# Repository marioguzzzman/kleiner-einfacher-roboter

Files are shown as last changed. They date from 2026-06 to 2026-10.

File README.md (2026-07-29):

# Mini Robot Swarm Unit — "Little Dog"

A small 3D-printed quadruped robot, built as one unit of a larger robotic swarm.
Each unit senses its surroundings, moves on four servo legs, and (from v2 onward)
has a synthesized "voice." This repository holds **two hardware/firmware
generations** of the same physical robot plus the **shared** mechanical body and
carrier PCB.

> The 3D body and the carrier PCB are common to both generations — only the
> microcontroller board and the firmware changed between v1 and v2.

---

## Two generations

| | **v1** | **v2** |
|---|---|---|
| Folder | [`v1/`](v1/) | [`v2/`](v2/) |
| MCU | Adafruit Feather ESP32 V2 | ESP32-C3 SuperMini |
| Servos | 4× MG90S | 4× MS18 (SG90-class) |
| Sensing | HC-SR04 ultrasonic | HC-SR04 ultrasonic (+ 1k/2k echo divider) |
| Audio | — | MAX98357A I2S amp + speaker ("modem voice") |
| Behavior | pose-based (sit / wave / walk / lay down) | trot + obstacle-stop (<10 cm) + voice on stop |
| I2C pins | GPIO21/22 | GPIO6/7 |
| Status | Phase 1 baseline | **electronics bring-up complete** |

**v2 is a continuation of v1**, not a separate project — same robot, new brain.

---

## Repository layout

```
kleiner-einfacher-roboter/
├── README.md                       ← you are here
├── LICENSE
├── robot_dog_pcb/                   KiCad carrier PCB          (SHARED)
├── little_robot_original_3d_stl/    printable body/legs/cover  (SHARED)
├── v1/   Feather ESP32 V2, pose-based
│   ├── README.md
│   ├── docs/          hardware.md · setup.md · code_explanation.md
│   └── src/           robot_dog.ino
└── v2/   ESP32-C3 SuperMini, walk + sensor + voice
    ├── README.md
    ├── firmware/
    │   ├── little_dog_walk/     ⭐ main program (walk + stop + voice)
    │   ├── little_dog_test_1/   full 5-part functionality test
    │   ├── little_dog_test_v2/  flag-based staged test
    │   ├── obstacle_stop/       walk + stop demo (simple chirp)
    │   └── diagnostics/         per-subsystem isolation sketches
    └── docs/          HANDOFF_WIRING.md · HANDOFF_LEARNINGS.md
```

---

## Shared hardware

- **Body:** `little_robot_original_3d_stl/` — `main_body.stl`, `leg.stl`, `cover.stl`.
  Based on the [Cobot Four-Servo-Legs Robot](https://makerworld.com/en/models/523448-cobot-four-servo-legs-and-distance-sensor-robot) on MakerWorld.
- **Carrier PCB:** `robot_dog_pcb/` — KiCad project (schematic, board, `.pdf` export).
  Modules mount as pluggable headers on the carrier.

---

## Getting started

- Building the **current** robot → see **[v2/README.md](v2/)** and
  [v2/docs/HANDOFF_WIRING.md](v2/docs/HANDOFF_WIRING.md) for the full wiring schematic.
- The **original** design → see **[v1/README.md](v1/)**.

---

## License

See [LICENSE](LICENSE). (Original note: all rights reserved.)

## Credits

- 3D model: [Cobot Four Servo Legs Robot](https://makerworld.com/en/models/523448-cobot-four-servo-legs-and-distance-sensor-robot) on MakerWorld
- Built with Arduino / ESP32, PCA9685, MAX98357A, and Adafruit libraries.

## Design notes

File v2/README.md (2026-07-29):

# v2 — ESP32-C3 SuperMini rebuild (walk + obstacle-stop + voice)

Second generation of the Little Dog quadruped. Same 3D body as
[v1](../v1/), but rebuilt around an **ESP32-C3 SuperMini** and given a
**synthesized voice** (a dial-up-modem "handshake") via an I2S amplifier.
Electronics bring-up is **complete and verified** — the robot trots, freezes
when something comes within 10 cm, and "speaks" when it stops.

> Full wiring (ASCII schematic, power rails, common-ground star) and the
> debugging lessons live in **[docs/HANDOFF_WIRING.md](docs/HANDOFF_WIRING.md)**
> and **[docs/HANDOFF_LEARNINGS.md](docs/HANDOFF_LEARNINGS.md)**. Read those first.

---

## Hardware

| Component | Role |
|---|---|
| ESP32-C3 SuperMini | MCU (USB-C, 3.3 V logic) |
| PCA9685 (HW-170) | 16-ch PWM servo driver, I2C @ **0x40** |
| 4× MS18 micro servos | legs (fore/aft swing) |
| HC-SR04 + 1k/2k divider | distance sensor ("eyes") |
| MAX98357A + speaker | I2S mono amp — the "voice" |
| 5 V bench supply (~3 A) | servo power into PCA9685 V+ |

## Pin map (ESP32-C3)

| GPIO | Net | | GPIO | Net |
|---|-----|-|---|-----|
| 0 | HC-SR04 TRIG | | 6 | PCA9685 SDA |
| 1 | HC-SR04 ECHO (÷) | | 7 | PCA9685 SCL |
| 3 | MAX98357A BCLK | | 10 | (unused — ex-OE) |
| 4 | MAX98357A LRC | | | |
| 5 | MAX98357A DIN | | | |

Power: PCA9685 **VCC ← 3.3 V** (logic) and **V+ ← 5 V** (servos) are separate.
MAX98357A **SD → 3.3 V** (enable), **GAIN → GND** (15 dB). **All grounds common**,
including the bench supply's negative. See the schematic in `docs/`.

---

## Firmware

Flagship program: **`firmware/little_dog_walk/`** — trots via diagonal pairs,
freezes all legs when an obstacle is within `STOP_CM` (10 cm), and plays the
modem-handshake voice on the stop edge. Tunables at the top: `g_volume`,
`SWING`, `STOP_CM`, cadence `delay()`.

| Sketch | Purpose |
|---|---|
| `little_dog_walk/` | ⭐ main: walk + obstacle-stop + modem voice |
| `little_dog_test_1/` | full 5-part test (center → per-leg → trot → distance → chirp) |
| `little_dog_test_v2/` | flag-based staged test (`TEST_LEGS/DISTANCE/AUDIO`) |
| `obstacle_stop/` | earlier walk+stop demo with a simple two-tone chirp |
| `diagnostics/esp32_alive/` | bare MCU sanity + LED blink |
| `diagnostics/motors_only/` | PCA9685 + servo sweep in isolation |
| `diagnostics/hold_center/` | park servos, measure holding current |
| `diagnostics/distance_only/` | HC-SR04 raw pulse + cm |
| `diagnostics/audio_only/` | amp test + I2S bytes-written diagnostic |
| `diagnostics/modem_chirp/` | standalone dial-up "voice" for tuning |

The `diagnostics/` sketches exist so each subsystem can be verified alone —
invaluable when something doesn't work (see the learnings doc).

---

## Build & flash

**Board:** ESP32C3 Dev Module. **Critical:** set **`USB CDC On Boot → Enabled`**
or the USB-C serial monitor stays blank.

Arduino IDE → Tools → Board → *esp32* → **ESP32C3 Dev Module**, then
`USB CDC On Boot: Enabled`, pick the port, Upload.

CLI equivalent:
```bash
arduino-cli compile --fqbn esp32:esp32:esp32c3:CDCOnBoot=cdc firmware/little_dog_walk
arduino-cli upload  -p COM3 --fqbn esp32:esp32:esp32c3:CDCOnBoot=cdc firmware/little_dog_walk
```
Libraries: **Adafruit PWM Servo Driver** (+ Adafruit BusIO). I2S uses the
built-in ESP32 `driver/i2s.h`.

---

## What changed from v1

- MCU **Feather ESP32 V2 → ESP32-C3 SuperMini** (3.3 V logic, native USB-C).
- I2C moved to **GPIO6/7** (v1 used 21/22); OE left unconnected (onboard pulldown).
- Added the **MAX98357A "voice"** and the **obstacle-stop** behavior.
- Servos **MG90S → MS18**; distance echo now through a **1k/2k divider**.

## Status / next

Bring-up done. Remaining before a proper directional gait:
**verify the leg map** (which PCA9685 channel drives which physical leg, and swing
direction) — run `little_dog_test_1` Part 2 and watch. Then add per-servo
direction sign + per-leg center trim. See `docs/HANDOFF_LEARNINGS.md`.

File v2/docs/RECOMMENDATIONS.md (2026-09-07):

# Recommendations — preparing to work on this project

A practical checklist for flashing and running the Little Dog (v2, ESP32-C3
SuperMini). Read this before a bench
session. Wiring details live in [HANDOFF_WIRING.md](HANDOFF_WIRING.md); the
*why* behind the gotchas is in [HANDOFF_LEARNINGS.md](HANDOFF_LEARNINGS.md).

---

## 1. Before you power on

- **Bench 5 V supply ON** into PCA9685 **V+** (servo power), limit ~3 A.
- **Common ground joined** — the bench supply's **(−) must tie into the same
  ground node** as the ESP32, PCA9685, sensor, and amp. If it doesn't, the
  servos get power but no valid signal and sit slack (looks like dead code, is
  actually wiring). See [HANDOFF_WIRING.md:93](HANDOFF_WIRING.md#L93).
- **Use a real USB *data* cable** (not charge-only), seated firmly. The
  SuperMini's USB-C jack is fragile — a flaky cable/connector is the #1 cause of
  the "port goes in and out."

## 2. Arduino IDE board setup

- **Board:** Tools → Board → **`esp32`** group (Espressif Systems) →
  **ESP32C3 Dev Module**. *Not* the "Arduino ESP32 Boards" group.
  - Confirm you're on the Espressif core: the Tools menu should show
    **USB CDC On Boot**, Flash Size, Partition Scheme, etc. If those options
    aren't there, you picked the wrong core.
- **USB CDC On Boot → Enabled.** Critical — without it the Serial Monitor stays
  blank on this board.
  - ⚠️ This is a **compile-time** option. Flipping the menu does nothing until
    you **re-upload** a sketch built with it enabled.
- **Baud:** Serial Monitor at **115200**.

## 3. If the COM port won't stay put

The SuperMini uses **native USB (USB-Serial/JTAG)**, so every reset
re-enumerates the port — it can appear to drop "in and out," and the COM number
hops on replug (we've seen COM3 / COM5 / COM9). This is expected behavior, not a
fault. Also try a **rear/motherboard USB port**, not a hub or front-panel port.

## 4. Uploading — force download mode

When a normal upload can't catch the cycling port, put the board into bootloader
mode by hand. This holds a stable port that doesn't run user code:

1. **Hold BOOT** (GPIO9) — keep holding.
2. While holding BOOT, **tap RESET** once, then release RESET.
3. **Release BOOT.** Now upload.

Order matters — BOOT must be held **across** the reset pulse; pressing both at
once does nothing. (One-button boards: hold BOOT while plugging in the USB.)

## 5. After the upload

- **"Hard resetting via RTS pin…" is normal** — it's just esptool pulsing reset
  so the chip boots your new sketch. Not an error.
- That reset **re-enumerates the USB port**, so the Serial Monitor from the
  upload is now stale. **Reselect the current COM** (re-check the port list) and
  **reopen the monitor at 115200**. Tap RESET once if nothing appears.

## 6. Verifying it actually works

- Serial Monitor should show `=== MOTORS-ONLY test ===` then
  **`found 0x40`** — that line confirms I2C + the PCA9685 are alive.
  `NONE found!` instead = SDA/SCL wiring or PCA9685 power, not the code.
- **Watch the legs, not just the log.** If servos sweep but the monitor is
  blank, the diagnostic is *passing* — only the logging is misrouted (see §2,
  USB CDC On Boot).
- Use the **`diagnostics/`** sketches to isolate one subsystem at a time
  (`motors_only`, `distance_only`, `audio_only`, …) — much faster than debugging
  the full `little_dog_walk` firmware.

## 7. Blank Serial Monitor — quick triage

1. Reopen the monitor on the **current** COM at **115200** (tap RESET first).
2. Still blank → **USB CDC On Boot = Enabled**, then **re-upload** (compile-time).
3. Still blank but **legs move** → the sketch is running; logging is on UART0
   (GPIO20/21), not USB. Fix via step 2.

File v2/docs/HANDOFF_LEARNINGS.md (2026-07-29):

# HANDOFF — Little Dog (unit #1) — WHAT WE LEARNED
Last updated: 2026-07-29 — bring-up + debugging session.
Companion: `HANDOFF_WIRING.md` (the physical wiring).

---

## HEADLINE
Full electronics bring-up is **DONE**. The robot walks, stops when something is
within 10 cm, and plays a dial-up-modem "voice" when it stops. Every subsystem
is verified working. The main remaining task is **leg-map verification** before a
real directional gait can be written.

---

## KEY LEARNINGS / GOTCHAS (in the order they bit us)

1. **PCA9685 OE has an onboard pull-down → leave OE UNCONNECTED.**
   Half-wired/floating OE was the cause of the long "servos only twitch" saga.
   Outputs are enabled by default. (Confirmed on Adafruit's pinout page.)

2. **"Servos twitch / don't move" with I2C working = signal/ground, not power.**
   Diagnosis ladder that worked:
   - I2C finds 0x40 → command path OK.
   - Servo **draws ~13 mA and sits slack** → NO valid PWM reaching it.
     A servo that's actually being driven **holds firm** and draws **100–200 mA**.
   - "Hold at center" test + feeling the horn (firm vs slack) is the fastest check.

3. **Bench-supply current is a LIMIT, not a push.**
   Raising the amp knob does not force current into the servos — they draw what
   they need. Setting it too LOW makes the supply fold back (voltage sags → twitch).
   Set the limit high (≈3 A) and keep **voltage at 5.0 V**.

4. **Common ground is mandatory between the bench supply and the ESP32.**
   Two separate power sources → the servo PWM needs a shared ground reference.
   Missing common ground = powered but slack servos.

5. **USB CDC On Boot must be ENABLED** for the SuperMini's USB-C serial.
   Default is Disabled → Serial goes to UART pins → **blank Serial Monitor**.
   FQBN: `esp32:esp32:esp32c3:CDCOnBoot=cdc`. Baud 115200.

6. **The I2S chirp hung the whole sketch.**
   `i2s_write(..., portMAX_DELAY)` blocks FOREVER if the buffer isn't draining,
   which froze the loop so Parts 4 & 5 (and even leg names) never printed.
   **Fix:** use a finite timeout `pdMS_TO_TICKS(50)` and bail if `bw==0`.
   Also: print the label BEFORE the sensor read, so a slow read can't hide it.

7. **MAX98357A silence debugging:**
   - **SD pin must be tied to 3.3V to ENABLE the amp.** It has an internal
     pull-down, so floating = shutdown = silent. A floating SD can even read a
     phantom 3.3V on a multimeter — don't trust it, wire it solidly.
   - Needs **all three** I2S lines: BCLK, LRC, DIN. Missing LRC = silent.
   - Its class-D output is **not measurable with a DMM** (balanced ~300 kHz PWM).
     Trust your ears, not the meter, on OUT+/OUT-.
   - **GAIN pin = hardware volume** (GAIN→GND = 15 dB max). Not software-settable.
   - **Software volume = scaling the sample amplitude** (`g_volume` 0..1). Both
     stages multiply: software amplitude → hardware GAIN → speaker.
   - Speaker is only 8Ω **0.25 W** — fine for brief chirps; a 4Ω 3W speaker later
     would be much louder and safer at full gain.
   - **Confirmed:** GAIN→GND (15 dB) is wired and works, `g_volume=1.0`, yet it's
     still not very loud — the **small speaker is the ceiling**, not the amp or
     the code. A slightly bigger speaker helped only marginally; a real 4Ω 3–5W
     driver in an enclosure is the fix if more volume is ever needed.

8. **I2C on GPIO6/7 works** and avoids the C3 strapping pins (GPIO2/8/9).
   One reference calls 6/7 "SPI-default," but `Wire.begin(6,7)` remaps fine and
   0x40 is found reliably. Only move it if you ever see I2C dropouts.

9. **Serial-read trick (for scripted reads):** on the C3's USB-JTAG, RTS = reset.
   Open the port with **RTS de-asserted** to avoid rebooting the board into the
   bootloader; the COM number also changes on replug (COM3 ↔ COM5).

---

## THE LITTLE PROGRAMS (sketch inventory)
All live as sibling folders in `C:\Users\mario\Downloads\`.

| Sketch | What it does (briefly) |
|---|---|
| **little_dog_walk/** | ⭐ FLAGSHIP. Trots (diagonal pairs); freezes all legs when something <10 cm; plays the modem-handshake "voice" on the stop edge. Has the full audio engine + median distance. |
| **little_dog_test_1/** | Original 5-part functionality test: center → move each leg one at a time (prints leg name — USE FOR LEG-MAP) → diagonal-pair trot preview → distance print → chirp. I2S now hang-proofed. |
| **esp32_alive/** | Bare MCU sanity check — boots, prints chip info, blinks onboard LED (GPIO8). Proves the ESP32 alone works. |
| **hold_center/** | Parks all 4 servos at center and holds; prints I2C + heartbeat. Used to measure holding current (firm/100–200 mA vs slack/13 mA). |
| **motors_only/** | PCA9685 + servos only (no sensor/audio). Big slow sweep per channel, then all together. Isolates the servo path. |
| **distance_only/** | HC-SR04 only. Prints raw echo pulse (µs) + cm. Confirmed the sensor + divider work. |
| **audio_only/** | MAX98357A only. Loud continuous tone; prints I2S bytes-written per burst to tell "I2S OK but amp silent" from "I2S not running." |
| **modem_chirp/** | Standalone dial-up "voice" so the sound can be tuned by ear on a loop. This sound is now folded into little_dog_walk. |
| **obstacle_stop/** | Earlier version of the flagship: walk + stop-at-10cm with a SIMPLE two-tone chirp (before the modem voice was integrated). Superseded by little_dog_walk. |
| **little_dog_test_v2/** | Mario's own sketch — NOT created in this session and not reviewed here. Provenance/contents unknown to the bring-up agent. |

---

## DONE (2026-07-29)
- Verified ESP32, I2C/PCA9685 (0x40), all 4 servos, HC-SR04, MAX98357A audio.
- Root-caused & fixed: OE twitch (leave OE unconnected), I2S hang (finite timeout),
  silent amp (SD→3.3V + all 3 I2S lines), blank serial (USB CDC On Boot).
- Wired bench 5V straight to PCA9685 V+ (buck bypassed for now).
- Built the modem "voice" + integrated walk + obstacle-stop + voice.

## STILL PENDING / NEXT
- **Leg-map verification (BLOCKING a real gait):** run Part 2 of `little_dog_test_1`
  and record, for ch0–ch3, which physical leg moves and which way (front/back) first.
- **Directional gait:** once mapped, add per-servo direction sign (cancel L/R mirror)
  and per-leg center-trim offsets. Current "trot" is an uncalibrated preview.
- **Battery + buck:** final untethered unit still needs a power decision (buck back in,
  or a second buck for the ESP32). Not acquired yet.
- **Bigger speaker** (4Ω 3–5W in an enclosure) is the only real way to get more
  volume — GAIN→GND + g_volume=1.0 are already maxed; the speaker is the limit.

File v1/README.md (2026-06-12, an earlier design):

# Mini Robot Swarm Unit

A desktop companion robot powered by ESP32 with pose-based movement system. This robot features 4 servos for leg and arm movement, ultrasonic distance sensing, and smooth interpolated motion.

Robot Concept

## Table of Contents

- [Overview](#overview)
- [Features](#features)
- [Hardware Requirements](#hardware-requirements)
- [Wiring Diagram](#wiring-diagram)
- [Software Setup](#software-setup)
- [Calibration](#calibration)
- [Usage](#usage)
- [Documentation](#documentation)
- [Troubleshooting](#troubleshooting)
- [Future Work](#future-work)

---

## Overview

This project is a Phase 1 implementation of a desktop companion robot that can perform basic movements:
- Sit
- Wave
- Walk forward/backward
- Lay down

The robot uses pose-based control, allowing for easy extension of new movements and behaviors.

**Hardware:** Adafruit Feather ESP32 V2 + PCA9685 PWM Driver + 4x MG90S Servos + HC-SR04 Ultrasonic Sensor

---

## Features

- Pose-based movement system with smooth transitions
- Calibration mode via built-in button (SW38)
- Servo mirroring for mirrored limb configurations
- Distance sensor integration for reactive behavior
- Modular code structure for easy extension

---

## Hardware Requirements

| Component | Description | Quantity |
|---|---|---|
| Adafruit Feather ESP32 V2 | Main microcontroller | 1 |
| PCA9685 16-Channel PWM Driver | Servo motor driver | 1 |
| MG90S Microservos | 9g metal gear servos | 4 |
| HC-SR04 Ultrasonic Sensor | Distance detection | 1 |
| External 5V Power Supply (2A+) | Servo power | 1 |
| Jumper Wires | Dupont cables | Various |

**Source for 3D Model:** [Cobot Four Servo Legs Robot on MakerWorld](https://makerworld.com/en/models/523448-cobot-four-servo-legs-and-distance-sensor-robot)

---

## Wiring Diagram

### PCA9685 to Feather ESP32 V2

```
PCA9685                           Feather ESP32 V2
-------                           ---------------
VCC (Logic Power)    ------>      3V (3.3V output)
GND (Ground)         ------>      GND
SDA (I2C Data)       ------>      SDA (GPIO 21)
SCL (I2C Clock)      ------>      SCL (GPIO 22)
V+ (Servo Power)    ------>      External 5V Supply

Green Terminal (External Power):
  +5V  ----> External 5V Supply (+)
  GND  ----> External 5V Supply (-)
        +--> Feather GND (REQUIRED!)
```

### Servo Channel Assignment

```
PCA9685 Servo Channels:
+---------+
| CH0     | ----> Left Leg
| CH1     | ----> Right Leg
| CH2     | ----> Left Arm
| CH3     | ----> Right Arm
+---------+
```

### HC-SR04 Distance Sensor

```
HC-SR04              Feather ESP32 V2
------              -----------------
VCC      ------>    USB (5V)
GND      ------>    GND
TRIG     ------>    A3 (GPIO 4)
ECHO     ------>    A2 (GPIO 3)
```

### Power Distribution

```
+============================================================+
|                      POWER FLOW                         |
+============================================================+

   USB (PC)                         External 5V Supply
       |                                    |
       v                                    v
  +=========+                        +============+
  | Feather  |                        | Green     |
  | ESP32 V2 |                        | Terminal  |
  +=========+                        +============+
       |                                    |
       | 3V ----> VCC (PCA9685 logic)      |
       | GND ---+> GND (PCA9685)            |
       |        |--> External GND bridge     |
       |        +--> Feather GND (CRITICAL!)|
       |                                    |
       v                                    v
  +========================================+
  |          PCA9685 Servo Driver          |
  +========================================+
       |                    |
       v                    v
  Servo Power (V+)      CH0-CH3
                         |
                         v
                    4x MG90S Servos

+============================================================+

IMPORTANT: All grounds must be connected together!
- Feather GND
- PCA9685 GND
- External 5V Supply GND
```

---

## Software Setup

### 1. Install ESP32 Board Definition

1. Open Arduino IDE
2. Go to **File > Preferences**
3. Add to "Additional Board Manager URLs":
   ```
   https://raw.githubusercontent.com/espressif/arduino-esp32/gh-pages/package_esp32_index.json
   ```
4. Go to **Tools > Board > Boards Manager**
5. Search "ESP32" and install "ESP32 by Espressif Systems"

### 2. Select Board and Port

1. **Board:** Tools > Board > Adafruit Feather ESP32-S2
2. **Port:** Tools > Port > (Select your COM port)

### 3. Install Libraries

Go to **Sketch > Include Library > Manage Libraries** and install:

| Library | Author |
|---|---|
| Adafruit PWM Servo Driver | Adafruit |
| NewPing | Tim Eckel |

### 4. Upload Code

1. Open `src/robot_dog/robot_dog.ino`
2. Click Upload button
3. Open Serial Monitor (115200 baud)

---

## Calibration

### Why Calibrate?

Standard servos (MG90S) don't remember their position when powered off. On startup, they may be at a random angle. Calibration gently sweeps all servos to a known neutral position (90°).

### How to Calibrate

1. **Hold the SW38 button** on the Feather ESP32 V2
2. While holding, power on or press the Reset button
3. The robot will enter calibration mode
4. All servos will slowly sweep from 0° to 90° (~3.6 seconds)
5. Robot holds neutral pose for 1 second
6. Calibration complete!

### Without Calibration

If SW38 is not pressed during boot, the robot applies the neutral pose immediately.

### Manual Re-calibration

During normal operation, press SW38 at any time to trigger re-calibration.

---

## Usage

### Default Behavior

The robot cycles through these behaviors in the main loop:

| Distance | Behavior |
|---|---|
| < 15 cm | Wave gesture |
| >= 15 cm or no object | Walk Forward → Walk Backward → Lay Down → Sit |

### Serial Monitor Output

```
=================================
Mini Robot Swarm Unit - Booting...
=================================
Applying neutral pose.
Robot ready!
Distance: 50 cm
Action: Walk Forward
Action: Walk Backward
Action: Lay Down
Action: Sit
Distance: 8 cm
Action: Wave
```

### Extending Movement Behaviors

Add new poses in the code:

```cpp
Pose wavePose = {90, 90, 60, 90};
applyPose(wavePose);
```

Use smooth transitions:

```cpp
smoothServo(LEFT_ARM, 90, 60, 10);
delay(200);
smoothServo(LEFT_ARM, 60, 120, 10);
```

---

## Documentation

For detailed information, see the docs folder:

| Document | Contents |
|---|---|
| [docs/hardware.md](docs/hardware.md) | Complete wiring diagrams and power distribution |
| [docs/setup.md](docs/setup.md) | Arduino IDE setup and troubleshooting |
| [docs/code_explanation.md](docs/code_explanation.md) | Detailed code breakdown |

---

## Troubleshooting

### Servos Don't Move

1. **Check ground connections** - All GNDs must be connected
2. **Verify external power** - Servos need 5V from external supply
3. **Test with I2C Scanner** - Verify PCA9685 is detected:
   ```cpp
   #include <Wire.h>
   void setup() {
     Wire.begin();
     Serial.begin(115200);
     for (byte i = 1; i < 127; i++) {
       Wire.beginTransmission(i);
       if (Wire.endTransmission() == 0) {
         Serial.print("I2C found: 0x");
         Serial.println(i, HEX);
       }
     }
   }
   ```

### Code Uploads Fail

1. Press and hold **BOOT button** while clicking Upload
2. Try a different USB-C cable (some are charge-only)
3. Install USB drivers (CP2104 or CH9102)

### Servos Move Wrong Direction

- Check `applyAngle()` function in code
- Right leg and both arms may need angle inversion
- Mechanical solution: Realign servo horn

### Robot Jerky Movement

- Calibration may be too fast: Increase delay in `calibrateServos()`
- Use `smoothServo()` for gradual transitions

---

## Future Work

### Phase 2 Goals

- [ ] Web interface control (WiFi)
- [ ] Mobile app integration
- [ ] TouchDesigner communication (OSC/WebSocket)
- [ ] Multiple robot coordination
- [ ] Sound responses
- [ ] Idle animations and breathing effects

---

## License

No license for now. All rights reserved.

---

## Credits

- 3D Model: [Cobot Four Servo Legs Robot](https://makerworld.com/en/models/523448-cobot-four-servo-legs-and-distance-sensor-robot) on MakerWorld
- Built with Arduino, ESP32, and Adafruit components

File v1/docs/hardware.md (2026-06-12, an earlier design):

# Hardware Guide

## Components List

| Component | Description | Quantity |
|---|---|---|
| Adafruit Feather ESP32 V2 | Main microcontroller with WiFi | 1 |
| PCA9685 16-Channel PWM Driver | Servo motor driver board | 1 |
| MG90S Microservos | 9g metal gear servos for legs and arms | 4 |
| HC-SR04 Ultrasonic Distance Sensor | For detecting nearby objects | 1 |
| External 5V Power Supply | 2A minimum for servos | 1 |
| Jumper Wires | Dupont cables for connections | Various |
| Breadboard | Optional, for organizing connections | 1 |

---

## Wiring Diagram

### PCA9685 to Feather ESP32 V2

```
+==============================================================+
|                    PCA9685 Servo Driver                     |
+==============================================================+
|                                                              |
|   VCC (Logic Power) ----+----> 3V  (Feather 3.3V output)    |
|   GND  (Ground) --------+----> GND (Feather GND)           |
|   SDA  (I2C Data) -------+----> SDA (Feather SDA/GPIO 21)    |
|   SCL  (I2C Clock) ------+----> SCL (Feather SCL/GPIO 22)    |
|   V+   (Servo Power) ---+----> External 5V Supply            |
|                                                              |
|   +========================================================+ |
|   |  Servo Channels (Yellow Header)                        | |
|   +========================================================+ |
|   | CH0: Left Leg                                         | |
|   | CH1: Right Leg                                        | |
|   | CH2: Left Arm                                         | |
|   | CH3: Right Arm                                        | |
|   +========================================================+ |
|                                                              |
|   External Power Input (Green Screw Terminal):               |
|   +5V -----> External 5V Power Supply (+)                   |
|   GND -----> External 5V Power Supply (-)                  |
|             +-> Feather GND (MUST be connected!)             |
|                                                              |
+==============================================================+
```

### HC-SR04 Distance Sensor to Feather ESP32 V2

```
+==============================================================+
|                  HC-SR04 Ultrasonic Sensor                  |
+==============================================================+

    +-----------+         Feather ESP32 V2
    |  HC-SR04  |
    +-----------+
    | VCC       |-----> USB (5V from Feather)
    | GND       |-----> GND (Feather GND)
    | TRIG      |-----> A3 (GPIO 4)
    | ECHO      |-----> A2 (GPIO 3)  [Optional: Use voltage divider]
    +-----------+

+==============================================================+
```

### Power Distribution Summary

```
+==============================================================+
|                     POWER FLOW DIAGRAM                      |
+==============================================================+

    USB Cable                     External 5V Supply
    from PC                           |
        |                             |
        v                             v
  +===========+               +===============+
  |  Feather  |               |   Green      |
  |  ESP32 V2 |               |  Terminal    |
  +===========+               +===============+
        |                             |
        | 3V -----> VCC (PCA9685 logic)
        | GND --+-> GND (PCA9685)
        |       |-> GND (External supply bridge)
        |       +-> Feather GND (CRITICAL!)
        |                             |
        v                             v
  +===============================+
  |        PCA9685 Servo Driver   |
  +===============================+
        |                   |
        v                   v
    Servo Power       Servo Channels
    (V+ rail)         CH0-CH3
                      |
                      v
                  Servos (4x)
                  MG90S

+==============================================================+
```

### Servo Channel Mapping

```
+==============================================================+
|               SERVO CHANNEL ASSIGNMENTS                     |
+==============================================================+

    PCA9685
    +-------+
    | CH0   |-----> Left Leg
    | CH1   |-----> Right Leg
    | CH2   |-----> Left Arm
    | CH3   |-----> Right Arm
    +-------+

    Each servo wire connection (looking at yellow header):
    +===+===+===+===+===+===+===+===+
    | G | V | S | G | V | S | G | V | ...  (GND, V+, Signal)
    +===+===+===+===+===+===+===+===+
      0   1   2   3   4   5   6   7  ...

+==============================================================+
```

---

## Critical Notes

### 1. Ground Connection (CRITICAL!)
All grounds MUST be connected together:
- Feather GND
- PCA9685 GND
- External 5V supply GND

Without this common ground, PWM signals will not work correctly.

### 2. Power Requirements
- Servos require 5V at 2A minimum
- USB power from Feather is NOT sufficient for multiple servos
- Use external 5V power supply connected to green terminal

### 3. Servo Signal Direction
The following servos are physically mirrored and need angle inversion:
- RIGHT_LEG (CH1): Inverted
- LEFT_ARM (CH2): Inverted
- RIGHT_ARM (CH3): Inverted

LEFT_LEG (CH0) is normal (no inversion).

---

## Optional: Voltage Divider for HC-SR04 ECHO

The HC-SR04 outputs 5V on ECHO, but Feather ESP32 uses 3.3V logic.
If you have resistors available, use this voltage divider:

```
ECHO pin ----[ 1k Ohm ]---- GPIO A2 (Pin 3)
                          |
                    [ 2k Ohm ]
                          |
                         GND
```

This creates a 3.3V signal from the 5V ECHO output.

**Note:** Many users report success without this divider for testing.
For permanent installations, add the voltage divider for safety.

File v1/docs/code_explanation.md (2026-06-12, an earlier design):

# Code Explanation

This document explains how the robot dog code works, section by section.

---

## Overview

The code controls a 4-servo desktop companion robot using:
- **ESP32** microcontroller (Feather ESP32 V2)
- **PCA9685** PWM driver for servo control
- **HC-SR04** ultrasonic sensor for distance detection

The robot can sit, wave, walk forward/backward, and lay down.

---

## Code Structure

```cpp
// 1. Configuration (Constants and Pin Definitions)
// 2. Library Objects (PWM driver and Ultrasonic sensor)
// 3. Structs and Helpers (Pose structure, angle functions)
// 4. Poses (neutralPose, sittingPose)
// 5. Calibration Functions
// 6. Movement Functions
// 7. Setup
// 8. Main Loop
```

---

## 1. Configuration

```cpp
#define TRIG_PIN 4   // HC-SR04 Trig (A3 on Feather)
#define ECHO_PIN 3   // HC-SR04 Echo (A2 on Feather)
#define CALIBRATION_BUTTON_PIN 0  // SW38 button
```

These constants define which GPIO pins are used for:
- Ultrasonic sensor (TRIG and ECHO)
- Calibration button (built-in SW38)

```cpp
#define SERVOMIN 150    // Min pulse for 0 degrees
#define SERVOMAX 600    // Max pulse for 180 degrees
```

PCA9685 pulse width mapping:
- `SERVOMIN = 150` → 0° position
- `SERVOMAX = 600` → 180° position

```cpp
#define LEFT_LEG 0     // PCA9685 Channel 0
#define RIGHT_LEG 1     // PCA9685 Channel 1
#define LEFT_ARM 2      // PCA9685 Channel 2
#define RIGHT_ARM 3     // PCA9685 Channel 3
```

Channel assignments for the 4 servos.

---

## 2. Servo Mirroring: applyAngle()

```cpp
int applyAngle(uint8_t channel, int angle) {
  if (channel == RIGHT_LEG || channel == RIGHT_ARM) {
    return 180 - angle;
  } else if (channel == LEFT_ARM) {
    return 180 - angle;
  }
  return angle;
}
```

**Purpose:** Handle servos that are physically mounted in opposite orientation.

**Why needed:** Some servos are mounted facing the opposite direction. When you send angle 90, a normal servo goes "straight" - but a mirrored servo goes "straight" when sent 90 as well, but that makes it move the opposite way. This function inverts the angle for mirrored servos.

**Mapping:**
| Channel | Inverted? | Reason |
|---|---|---|
| LEFT_LEG (0) | No | Mounted normally |
| RIGHT_LEG (1) | Yes | Physically mirrored |
| LEFT_ARM (2) | Yes | Physically mirrored |
| RIGHT_ARM (3) | Yes | Physically mirrored |

---

## 3. Safe Range: clampAngle()

```cpp
int clampAngle(int angle) {
  return constrain(angle, 10, 170);
}
```

**Purpose:** Prevent servos from moving to their mechanical limits.

**Why:** Servos can strain, buzz, or stall at 0° and 180°. This function limits angles to a safe range (10°-170°).

---

## 4. Pulse Conversion: angleToPulse()

```cpp
int angleToPulse(int ang) {
  return map(clampAngle(ang), 0, 180, SERVOMIN, SERVOMAX);
}
```

**Purpose:** Convert an angle (0-180) to a PCA9685 pulse width value.

**Process:**
1. Clamp angle to safe range (10-170)
2. Map 0-180 to SERVOMIN-SERVOMAX (150-600)

---

## 5. Set Single Servo: setServo()

```cpp
void setServo(uint8_t channel, int angle) {
  int corrected = applyAngle(channel, angle);
  pwm.setPWM(channel, 0, angleToPulse(corrected));
}
```

**Purpose:** Set a single servo to a specific angle.

**Process:**
1. Apply mirroring correction (`applyAngle`)
2. Convert to pulse width (`angleToPulse`)
3. Send to PCA9685 (`pwm.setPWM`)

---

## 6. Pose System

```cpp
struct Pose {
  int leftLeg;
  int rightLeg;
  int leftArm;
  int rightArm;
};

Pose neutralPose = {90, 90, 90, 90};
Pose sittingPose = {0, 180, 90, 90};
```

**Purpose:** Define and apply full-body poses.

**How it works:**
- A `Pose` is a struct containing angles for all 4 servos
- `neutralPose` = all limbs at 90° (upright)
- `sittingPose` = legs bent inward, arms neutral

---

## 7. Apply Pose: applyPose()

```cpp
void applyPose(Pose p) {
  setServo(LEFT_LEG, p.leftLeg);
  setServo(RIGHT_LEG, p.rightLeg);
  setServo(LEFT_ARM, p.leftArm);
  setServo(RIGHT_ARM, p.rightArm);
  currentPose = p;
}
```

**Purpose:** Apply a complete pose to all 4 servos at once.

---

## 8. Smooth Movement: smoothServo()

```cpp
void smoothServo(uint8_t channel, int fromAngle, int toAngle, int stepDelay) {
  int step = (fromAngle < toAngle) ? 1 : -1;
  for (int angle = fromAngle; angle != toAngle; angle += step) {
    setServo(channel, angle);
    delay(stepDelay);
  }
  setServo(channel, toAngle);
}
```

**Purpose:** Move a servo gradually instead of snapping instantly.

**Example:**
```cpp
smoothServo(LEFT_ARM, 90, 60, 10);
// Moves arm from 90 to 60 degrees
// One degree at a time with 10ms delay between each step
```

**Why use it:** Creates more natural, organic movement instead of robotic snapping.

---

## 9. Calibration: calibrateServos()

```cpp
void calibrateServos() {
  Serial.println("Entering calibration mode...");
  for (int angle = 0; angle <= 90; angle++) {
    setServo(LEFT_LEG, angle);
    setServo(RIGHT_LEG, angle);
    setServo(LEFT_ARM, angle);
    setServo(RIGHT_ARM, angle);
    delay(40);
  }
  Serial.println("Calibration complete!");
  delay(1000);
}
```

**Purpose:** Gently move all servos to neutral position (90°) on startup.

**When to use:**
- Press and hold **SW38 button** (GPIO 0) during boot
- Robot enters calibration mode
- All servos sweep slowly from 0° to 90°
- Takes about 3.6 seconds (90 steps × 40ms)

**Why needed:** Standard servos don't remember their position when powered off. Calibration ensures all limbs start from a known position.

---

## 10. Setup

```cpp
void setup() {
  Serial.begin(115200);
  pwm.begin();
  pwm.setPWMFreq(50);  // 50Hz = standard servo frequency

  pinMode(CALIBRATION_BUTTON_PIN, INPUT);

  if (digitalRead(CALIBRATION_BUTTON_PIN) == LOW) {
    calibrateServos();
  } else {
    applyPose(neutralPose);
  }
}
```

**Process:**
1. Start serial communication (115200 baud)
2. Initialize PCA9685
3. Set PWM frequency to 50Hz
4. Check if SW38 button is pressed
   - Yes → Run calibration
   - No → Apply neutral pose

---

## 11. Main Loop

```cpp
void loop() {
  int distance = sonar.ping_cm();

  if (distance > 0 && distance < 15) {
    wave();
  } else {
    walkForward();
    delay(1000);
    walkBackward();
    delay(1000);
    layDown();
    delay(1000);
    sit();
  }
}
```

**Behavior:**
- Reads distance from ultrasonic sensor
- If something is within 15cm → Wave
- Otherwise → Cycle through walk forward, walk backward, lay down, sit

---

## Key Functions Summary

| Function | Purpose |
|---|---|
| `applyAngle()` | Mirror servo angles for reversed servos |
| `clampAngle()` | Limit angles to safe range (10-170) |
| `angleToPulse()` | Convert angle to PWM pulse width |
| `setServo()` | Set one servo to an angle |
| `applyPose()` | Apply all 4 servo angles at once |
| `smoothServo()` | Move servo gradually with interpolation |
| `calibrateServos()` | Sweep all servos to neutral position |
| `sit()`, `wave()`, etc. | Predefined movement patterns |

---

## Extending the Code

### Adding New Poses

```cpp
Pose myNewPose = {120, 60, 90, 90};

// Apply it:
applyPose(myNewPose);
```

### Adding Smooth Transitions

```cpp
// Move from current pose to new pose smoothly
smoothServo(LEFT_LEG, currentPose.leftLeg, 120, 10);
smoothServo(RIGHT_LEG, currentPose.rightLeg, 60, 10);
smoothServo(LEFT_ARM, currentPose.leftArm, 90, 10);
smoothServo(RIGHT_ARM, currentPose.rightArm, 90, 10);
```

### Custom Movement Sequences

```cpp
void customDance() {
  for (int i = 0; i < 3; i++) {
    applyPose(sittingPose);
    delay(500);
    applyPose(neutralPose);
    delay(500);
  }
}
```

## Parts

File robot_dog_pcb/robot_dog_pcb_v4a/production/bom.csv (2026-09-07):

Designator | Footprint | Quantity | Value | LCSC Part #
C1 | C_Radial_D10.0mm_H12.5mm_P5.00mm | 1 | 1000uF
J1 | AMASS_XT30PW-M_1x02_P2.50mm_Horizontal | 1 | MAIN POWER
J2, J4 | PinSocket_1x03_P2.54mm_Vertical | 2 | GPIO
J3 | PinSocket_1x04_P2.54mm_Vertical | 1 | HC-SR04
J5, J6 | PinSocket_1x03_P2.54mm_Vertical | 2 | Extra power
R2 | R_Axial_DIN0207_L6.3mm_D2.5mm_P7.62mm_Horizontal | 1 | 2K
R3 | R_Axial_DIN0207_L6.3mm_D2.5mm_P7.62mm_Horizontal | 1 | 1k
U1 | MODULE_ESP32-C3_SUPERMINI_TH | 1 | ESP32-C3_SUPERMINI_TH
U2 | Adafruit-MAX98357-I2S-Amp-Breakout | 1 | MAX98357-I2S-Amp
U3 | PCB ONLY Adafruit-16-Channel-PWM-Servo-Driver-PCB | 1 | Adafruit-16-Channel-PWM-Servo-Driver-PCB

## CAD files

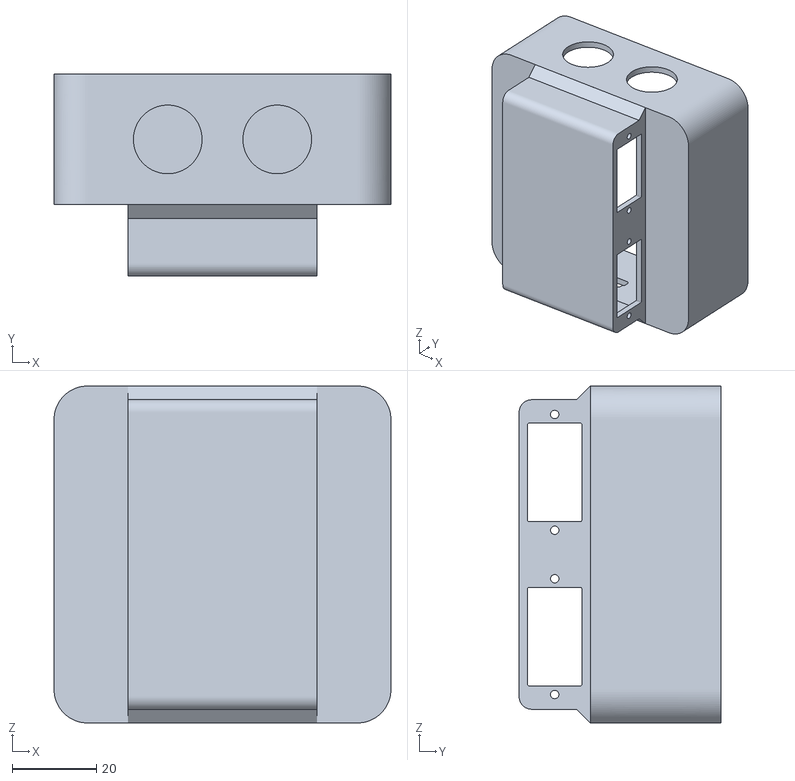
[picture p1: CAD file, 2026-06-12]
little_robot_original_3d_stl/main_body.stl
80.0 x 47.9 x 80.0

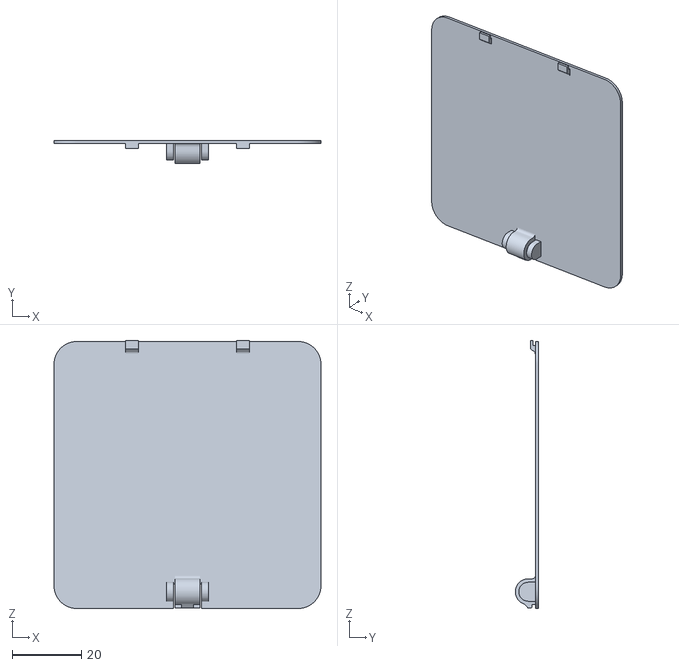
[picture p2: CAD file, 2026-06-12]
little_robot_original_3d_stl/cover.stl
77.2 x 6.75 x 77.5

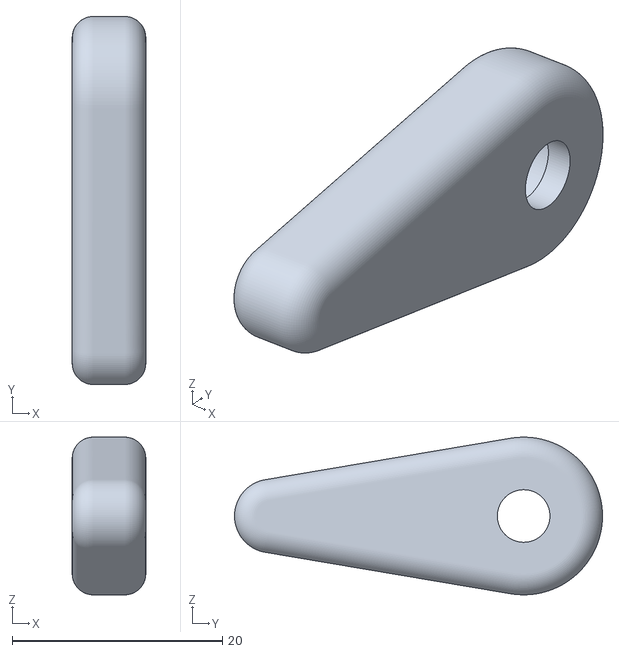
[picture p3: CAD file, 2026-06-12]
little_robot_original_3d_stl/leg.stl
7.00 x 35.0 x 15.0

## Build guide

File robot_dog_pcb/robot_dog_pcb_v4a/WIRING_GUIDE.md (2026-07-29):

# v3 Carrier Schematic — Wiring Guide (matches robot v2)

The carrier holds four **pluggable module headers** (modules stay removable/repairable):
U1 ESP32-C3 SuperMini · U2 MAX98357A amp · U3 PCA9685 servo driver · J3 HC-SR04 sensor.
Servos plug into the PCA9685 module directly; the speaker wires to the amp module
directly — so the carrier only carries the interconnect + divider + power.

Connect by **net label** (two same-named labels = one net) for signals, and
**power symbols** (+5V / +3V3 / GND) for the rails.

## Signal nets
| Net label | Pin A | Pin B |
|---|---|---|
| TRIG | U1 GPIO0 | J3 TRIG pin |
| ECHO | U1 GPIO1 | divider node (below) |
| BCLK | U1 GPIO3 | U2 BCLK |
| LRCLK | U1 GPIO4 | U2 LRCLK |
| DIN | U1 GPIO5 | U2 DIN |
| SDA | U1 GPIO6 | U3 SDA |
| SCL | U1 GPIO7 | U3 SCL |

## ECHO divider (5V echo -> 3.3V)
```
J3 ECHO(5V) --[ R1 = 1k ]--+-- node (label ECHO -> U1 GPIO1)
                           |
                        [ R2 = 2k ]
                           |
                          GND
```

## Power
- +3V3 (from U1 3V3) -> U3 VCC  and  U2 SD          (SD high = amp enabled)
- +5V  (screw-terminal rail) -> U3 V+, U2 VDD, J3 VCC
- GND  (common) -> U1 GND, U2 GND, U3 GND, J3 GND, R2 bottom, U2 GAIN (GAIN->GND = 15 dB)
- U3 ~OE  -> leave unconnected (place a no-connect flag; onboard pulldown enables outputs)
- U2 VO+/VO- -> no-connect on carrier (speaker attaches at the amp module)

## Power source (upstream, external to carrier)
2S LiPo 7.4V (~1500-2200 mAh) -> main switch (SW1) -> XL4005 buck @ 5.0V -> +5V rail.
ESP32 onboard LDO makes 3.3V. 470-1000 uF cap on the 5V rail near the servos.
Do NOT feed USB and battery into the ESP32 5V pin at once (isolate battery when
programming, or add a Schottky diode on the battery->5V path).

## After wiring
Inspect -> Electrical Rules Checker (ERC). Fix any "unconnected pin" (a label that
didn't land exactly on the pin end). OE, VO+/VO- should be marked no-connect.

## Corrections vs the current V2 sheet (align to the working firmware)
The existing sheet's I2C/I2S pins and the amp enable don't match the firmware
verified on the bench. Apply these:

U1 ESP32-C3:
  GPIO0  -> label TRIG          (was nc)
  GPIO1  -> label ECHO          (was nc; from divider node)
  GPIO3  -> I2S_BCLK            (keep)
  GPIO4  -> I2S_LRCLK           (keep)
  GPIO5  -> label I2S_DOUT      (was nc)
  GPIO6  -> SDA                 (was I2S_DOUT)
  GPIO7  -> SCL                 (was SDA)
  GPIO8  -> nc                  (was SCL)
  3V3 -> +3V3 ,  5V -> +5V ,  GND -> GND

U2 MAX98357A:
  SD   -> +3V3   (was nc)   *** critical: floating SD = silent amp ***
  GAIN -> GND    (was nc)   (15 dB)
  VDD +5V, GND GND, DIN I2S_DOUT, BCLK I2S_BCLK, LRCLK I2S_LRCLK   (keep)
  VO+/VO- -> nc  (speaker attaches at the module)

U3 PCA9685:
  VCC -> +3V3   (was "3.5V ESP"; make sure it is 3.3 V, not 5 V)
  V+  -> +5V    (servo power)
  ~OE -> nc     (remove OE label; onboard pulldown enables outputs)
  SDA / SCL / GND keep ;  PWM_0..15 -> nc

J3 HC-SR04:  pin4 VCC -> +5V ,  pin3 TRIG -> TRIG ,  pin2 ECHO -> divider ,  pin1 GND -> GND

Checks:
  - I2C pull-ups (4.7k) top -> +3V3, NOT +5V  (protect ESP32 3.3 V pins)
  - No-connect flags on: U1 GPIO2/8/9/10/20/21, U3 PWM_0..15, U3 ~OE, U2 VO+/VO-

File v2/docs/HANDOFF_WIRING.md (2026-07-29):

# HANDOFF — Little Dog (unit #1) — WIRING & CONNECTIONS
Last updated: 2026-07-29 — full electronics bring-up completed this session.
Status: **ALL SUBSYSTEMS WORKING** (servos, I2C/PCA9685, HC-SR04 distance, MAX98357A audio).
Flagship firmware: `little_dog_walk/little_dog_walk.ino` (walk + obstacle-stop + modem voice).

> This file = the physical wiring as actually built and verified on the bench.
> Companion file: `HANDOFF_LEARNINGS.md` (why things are wired this way + gotchas).

---

## MODULES
- **MCU:** ESP32-C3 SuperMini (USB-C, 3.3V logic)
- **Servo driver:** PCA9685 (HW-170, 16ch, I2C @ **0x40**)
- **Distance:** HC-SR04 (5V version) + 1k/2k ECHO divider
- **Audio:** MAX98357A (I2S mono class-D amp) + 8Ω 0.25W speaker
- **Actuators:** 4× MS18 micro servos (SG90-class), fore/aft swing
- **Servo power (bench):** lab supply set to **5.0 V, limit ~3 A**, straight into PCA9685 V+.
  (The XL4005 buck from the earlier plan is currently **BYPASSED** — not in the circuit.)

---

## SYSTEM SCHEMATIC (as built)

```
        USB-C ──► [PC]  (powers ESP32 + native-USB serial, and VBUS=5V rail)
          │
          ▼
 ┌───────────────────────────┐
 │   ESP32-C3 SuperMini      │       ── I2C ──►  ┌──────────────────────┐
 │   (3.3 V logic)           │  GPIO6 SDA ─────► │   PCA9685  (0x40)    │
 │                           │  GPIO7 SCL ─────► │                      │
 │  GPIO0 ───────────────────┼──────────► TRIG   │  VCC ◄─ 3.3V (logic) │
 │  GPIO1 ◄──[1k/2k divider]─┼─── ECHO           │  V+  ◄─ BENCH 5V     │
 │  GPIO3 ───────────────────┼──► BCLK           │  OE  ─ (unconnected) │
 │  GPIO4 ───────────────────┼──► LRC            │  ch0 ─► servo BL(?)  │
 │  GPIO5 ───────────────────┼──► DIN            │  ch1 ─► servo BR(?)  │
 │  GPIO10  (unused, ex-OE)  │                   │  ch2 ─► servo FL(?)  │
 │                           │                   │  ch3 ─► servo FR(?)  │
 │  3.3V ─┬─► PCA9685 VCC     │                   └──────────────────────┘
 │        └─► MAX98357A SD    │                    (? = leg map UNVERIFIED)
 │  5V   ─┬─► HC-SR04 VCC     │
 │        └─► MAX98357A Vin   │       ┌──────────────────────┐
 │  GND ─► COMMON GROUND ─────┼─────► │   MAX98357A          │
 └───────────────────────────┘  BCLK►│  BCLK  LRC  DIN       │
                                 LRC► │  Vin ◄─ 5V            │
                                 DIN► │  SD  ◄─ 3.3V (ENABLE) │
                                      │  GAIN ─ GND (15 dB)*  │
                                      │  OUT+ ─┐              │
                                      │  OUT- ─┴─► 8Ω speaker │
                                      └──────────────────────┘

   HC-SR04:  VCC◄5V   GND►common   TRIG◄GPIO0   ECHO►divider►GPIO1
```
\* GAIN→GND is CONNECTED (max 15 dB) and working. Note: overall loudness is
   limited by the small speaker, not the amp — even a slightly bigger speaker
   was only marginally louder. A 4Ω 3–5W driver in a small enclosure is what
   would actually get loud. `g_volume` is currently 1.0 in the firmware.

---

## PIN MAP (ESP32-C3 → everything)

| GPIO  | Net | Notes |
|---|---|---|
| GPIO0 | HC-SR04 TRIG | direct, 3.3V out is fine for trigger |
| GPIO1 | HC-SR04 ECHO (via divider)  | 5V echo dropped to 3.3V by 1k/2k |
| GPIO2 | — | strapping pin, leave empty |
| GPIO3 | MAX98357A BCLK | I2S bit clock |
| GPIO4 | MAX98357A LRC | I2S word select |
| GPIO5 | MAX98357A DIN | I2S data |
| GPIO6 | PCA9685 SDA | `Wire.begin(6,7)` |
| GPIO7 | PCA9685 SCL | |
| GPIO8 | — | strapping + onboard LED, leave empty |
| GPIO9 | — | strapping + boot button, leave empty |
| GPIO10| **UNUSED** (was PCA9685 OE) | OE now left unconnected — see below |
| GPIO20| — (UART RX, free) | |
| GPIO21| — (UART TX, free) | |

---

## POWER RAILS

| Rail | Source | Feeds |
|---|---|---|
| **3.3V** | ESP32 3.3V pin | PCA9685 **VCC** (logic), MAX98357A **SD** (enable) |
| **5V (logic side)** | ESP32 5V pin (USB VBUS) | HC-SR04 **VCC**, MAX98357A **Vin** |
| **5V (servo side)** | **bench supply, 5.0V / ~3A limit** | PCA9685 **V+** (servo power ONLY) |
| **GND** | common star node | everything below |

> IMPORTANT: PCA9685 **VCC (3.3V logic)** and **V+ (5V servo power)** are SEPARATE
> on purpose. Do NOT feed VCC from 5V. Servo current lives on V+ only.

### COMMON GROUND (single net — star-joined)
All of these MUST be one electrical node:
- ESP32 GND
- PCA9685 GND (header + screw terminal)
- **Bench supply (−)**  ← the servo supply's negative MUST join here
- MAX98357A GND
- HC-SR04 GND
- bottom of ECHO divider (R2 → GND)

If the bench (−) is not tied to this node, servos get power but **no valid signal**
(they draw ~13 mA and sit slack). This bit us hard — see `HANDOFF_LEARNINGS.md`.

---

## ECHO DIVIDER (built on perfboard)

```
 HC-SR04 ECHO (5V) ──[ R1 = 1k ]──┬──► GPIO1   (junction ≈ 3.3V)
                                  │
                              [ R2 = 2k ]
                                  │
                                 GND (common)
```
TRIG has no divider (it's an output from the ESP32).

---

## OE — why it's disconnected (do NOT re-wire it)
The PCA9685 breakout has an **onboard pull-down on OE**, so OE floats to LOW =
outputs **enabled by default**. Leave OE **unconnected**. Driving it from GPIO10
is unnecessary and, half-wired/floating, caused the "servo twitch" saga this
session. Confirmed against Adafruit's PCA9685 pinout docs.
(If you ever want a software kill-switch back, wire OE to a spare GPIO and drive
it HIGH=disable / LOW=enable — but that's optional.)

---

## SERVO REFERENCE
- 50 Hz, 4096 ticks = 20 ms.  1.0ms=205 · **1.5ms=307 (CENTER)** · 2.0ms=410
- Firmware uses `CENTER=307`, `SWING=60` (gentle, protects cheap gears).
- **Leg map is UNVERIFIED** (ch0..3 → which physical leg + swing direction).
  Run Part 2 of `little_dog_test_1.ino` and watch. This blocks a real directional gait.

---

## TOOLCHAIN (for flashing)
- arduino-cli (bundled with Arduino IDE):
  `C:\Users\mario\AppData\Local\Programs\Arduino IDE\resources\app\lib\backend\resources\arduino-cli.exe`
- Board: **ESP32C3 Dev Module**, FQBN with USB serial:
  `esp32:esp32:esp32c3:CDCOnBoot=cdc`
- In Arduino IDE: Tools → Board → **esp32 → ESP32C3 Dev Module**, and
  **USB CDC On Boot → Enabled** (else Serial Monitor is blank).
- Port hops between COM3/COM5 on replug — re-check `arduino-cli board list`.
```bash
"C:\Users\mario\AppData\Local\Programs\Arduino IDE\resources\app\lib\backend\resources\arduino-cli.exe" compile --fqbn esp32:esp32:esp32c3:CDCOnBoot=cdc "C:\Users\mario\Downloads\little_dog_walk"
```

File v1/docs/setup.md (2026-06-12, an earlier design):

# Software Setup Guide

## Arduino IDE Setup

### Step 1: Install ESP32 Board Definitions

1. Open Arduino IDE
2. Go to **File > Preferences**
3. In the "Additional Board Manager URLs" field, add:
   ```
   https://raw.githubusercontent.com/espressif/arduino-esp32/gh-pages/package_esp32_index.json
   ```
4. Click "OK"
5. Go to **Tools > Board > Boards Manager**
6. Search for "ESP32"
7. Install "ESP32 by Espressif Systems"

### Step 2: Select Your Board

1. Connect your Feather ESP32 V2 via USB-C
2. Go to **Tools > Board**
3. Select **"Adafruit Feather ESP32-S2"**
4. Go to **Tools > Port**
5. Select the COM port (e.g., COM4, /dev/ttyUSB0)

### Step 3: Install Required Libraries

1. Go to **Sketch > Include Library > Manage Libraries**
2. Search for and install these libraries:

| Library | Author | Purpose |
|---|---|---|
| Adafruit PWM Servo Driver | Adafruit | PCA9685 control |
| NewPing | Tim Eckel | HC-SR04 ultrasonic sensor |

### Step 4: Verify Board Connection

Upload this test sketch to verify connection:

```cpp
void setup() {
  Serial.begin(115200);
  Serial.println("ESP32 connected!");
}

void loop() {
}
```

Open **Tools > Serial Monitor** (Ctrl+Shift+M) and set baud to **115200**.
You should see "ESP32 connected!" printed.

---

## Troubleshooting Board Connection

### Board Not Detected?

1. Try a different USB-C cable (some are charge-only)
2. Press the **BOOT** button on Feather while uploading
3. Install USB drivers:
   - **CP2104** driver for older Feather boards
   - **CH9102** driver for newer boards

### No COM Port Visible?

Windows:
```
1. Open Device Manager (Win + R, type "devmgmt.msc")
2. Look under "Ports (COM & LPT)"
3. Install driver if needed
```

Linux:
```bash
ls /dev/ttyUSB*
ls /dev/ttyACM*
```

macOS:
```bash
ls /dev/tty.*
```

---

## Uploading the Code

1. Open `src/robot_dog/robot_dog.ino` in Arduino IDE
2. Verify board settings:
   - Board: Adafruit Feather ESP32-S2
   - Port: (Your COM port)
   - Upload Speed: 115200
3. Click the **Upload** button (arrow icon)
4. Wait for "Done uploading"
5. Open Serial Monitor to see robot output

---

## Finding Your COM Port

### Windows - Device Manager
1. Press `Windows + R`
2. Type `devmgmt.msc`
3. Expand "Ports (COM & LPT)"
4. Look for "Silicon Labs CP210x" or "USB Serial Device"

### macOS - Terminal
```bash
ls /dev/tty.SLAB_USBtoUART
```

### Linux - Terminal
```bash
ls /dev/ttyUSB*
ls /dev/ttyACM*
```

### Quick Trick
1. Unplug the Feather
2. Note the COM ports listed
3. Plug in the Feather
4. The NEW port that appears is your board

---

## Serial Monitor Settings

- Baud Rate: **115200**
- Line Ending: **Newline** or **Both NL & CR**

Expected output on boot:
```
=================================
Mini Robot Swarm Unit - Booting...
=================================
Applying neutral pose.
Robot ready!
Distance: XX cm
```

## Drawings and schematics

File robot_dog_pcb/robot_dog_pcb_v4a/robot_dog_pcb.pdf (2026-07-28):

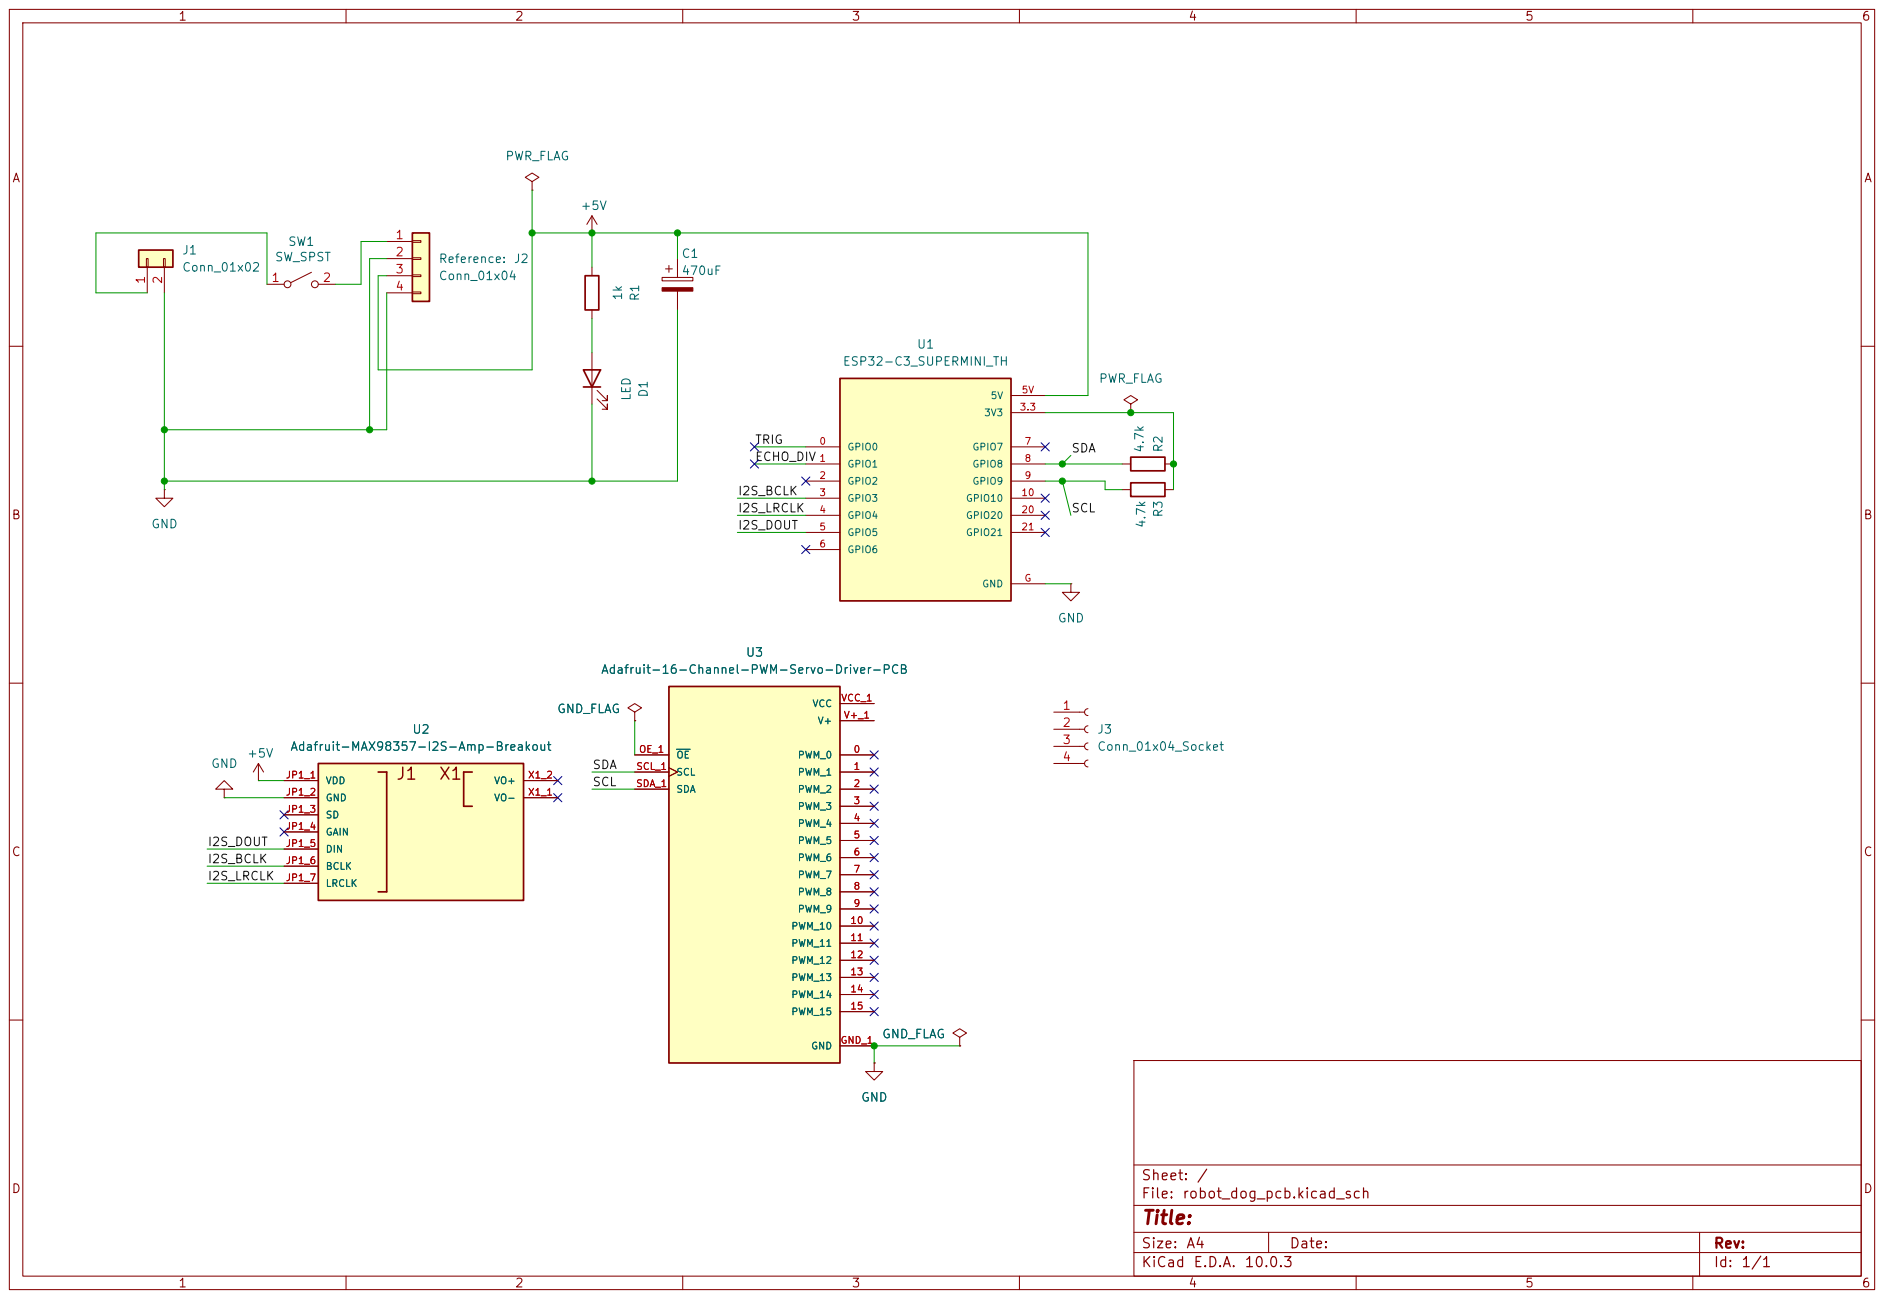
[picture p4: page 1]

Adafruit-16-Channel-PWM-Servo-Driver-PCB

Size: A4 | Rev:
KiCad E.D.A. 10.0.3 | Id: 1/1

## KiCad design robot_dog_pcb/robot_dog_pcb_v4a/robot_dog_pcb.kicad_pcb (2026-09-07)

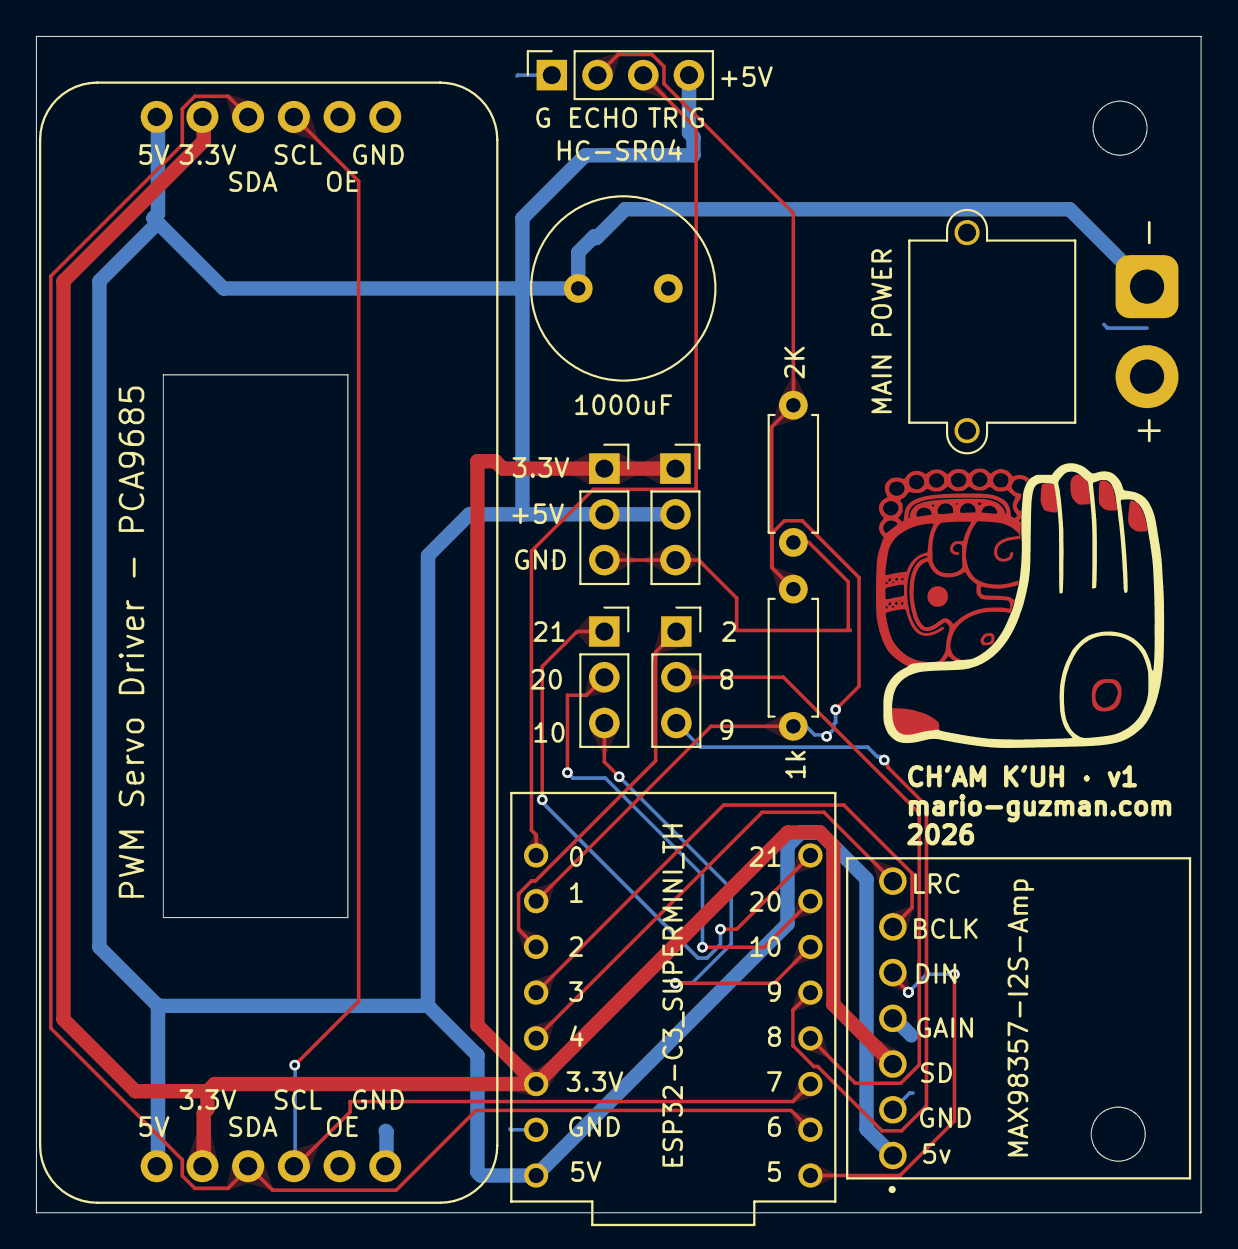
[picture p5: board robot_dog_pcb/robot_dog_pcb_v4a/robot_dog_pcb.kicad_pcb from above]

Board: 2 copper layers, 64.7 x 65.3 mm, 14 parts (0 on the bottom side), 16 nets.

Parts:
C1: 1000uF; C_Radial_D10.0mm_H12.5mm_P5.00mm
H1, H3: MountingHole; MountingHole_3mm
J1: MAIN POWER; AMASS_XT30PW-M_1x02_P2.50mm_Horizontal
J2, J4: GPIO; PinSocket_1x03_P2.54mm_Vertical
J3: HC-SR04; PinSocket_1x04_P2.54mm_Vertical
J5, J6: Extra power; PinSocket_1x03_P2.54mm_Vertical
R2: 2K; R_Axial_DIN0207_L6.3mm_D2.5mm_P7.62mm_Horizontal
R3: 1k; R_Axial_DIN0207_L6.3mm_D2.5mm_P7.62mm_Horizontal
U1: ESP32-C3_SUPERMINI_TH; MODULE_ESP32-C3_SUPERMINI_TH
U2: MAX98357-I2S-Amp; Adafruit-MAX98357-I2S-Amp-Breakout
U3: Adafruit-16-Channel-PWM-Servo-Driver-PCB; PCB ONLY Adafruit-16-Channel-PWM-Servo-Driver-PCB

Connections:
/BCLK: U1.3 (GPIO3), U2.JP1_6 (BCLK)
/DIN: U1.5 (GPIO5), U2.JP1_5 (DIN)
/ECHO: J3.2, R2.2, R3.1, R3.2, U1.1 (GPIO1)
/GPI02: J4.1, U1.2 (GPIO2)
/GPI08: J4.2, U1.8 (GPIO8)
/GPI09: J4.3, U1.9 (GPIO9)
/GPI10: J2.3, U1.10 (GPIO10)
/GPI020: J2.2, U1.20 (GPIO20)
/GPI021: J2.1, U1.21 (GPIO21)
/LRCLK: U1.4 (GPIO4), U2.JP1_7 (LRCLK)
/SCL: U1.7 (GPIO7), U3.SCL_1 (SCL), U3.SCL_2 (SCL)
/SDA: U1.6 (GPIO6), U3.SDA_1 (SDA), U3.SDA_2 (SDA)
/TRIG: J3.3, U1.0 (GPIO0)
GND: C1.2, J1.2 (GND_MAIN), J3.1 (GND), J5.3, J6.3, R2.1, U1.G (GND), U2.JP1_2 (GND), U2.JP1_4 (GAIN), U3.GND_1 (GND), U3.GND_2 (GND)
V+: C1.1, J1.1 (5V_MAIN), J3.4, J5.2, J6.2, U1.5V, U2.JP1_1 (VDD), U3.V+_1 (V+), U3.V+_2 (V+)
VCC: J5.1, J6.1, U1.3.3 (3V3), U2.JP1_3 (SD), U3.VCC_1 (VCC), U3.VCC_2 (VCC)

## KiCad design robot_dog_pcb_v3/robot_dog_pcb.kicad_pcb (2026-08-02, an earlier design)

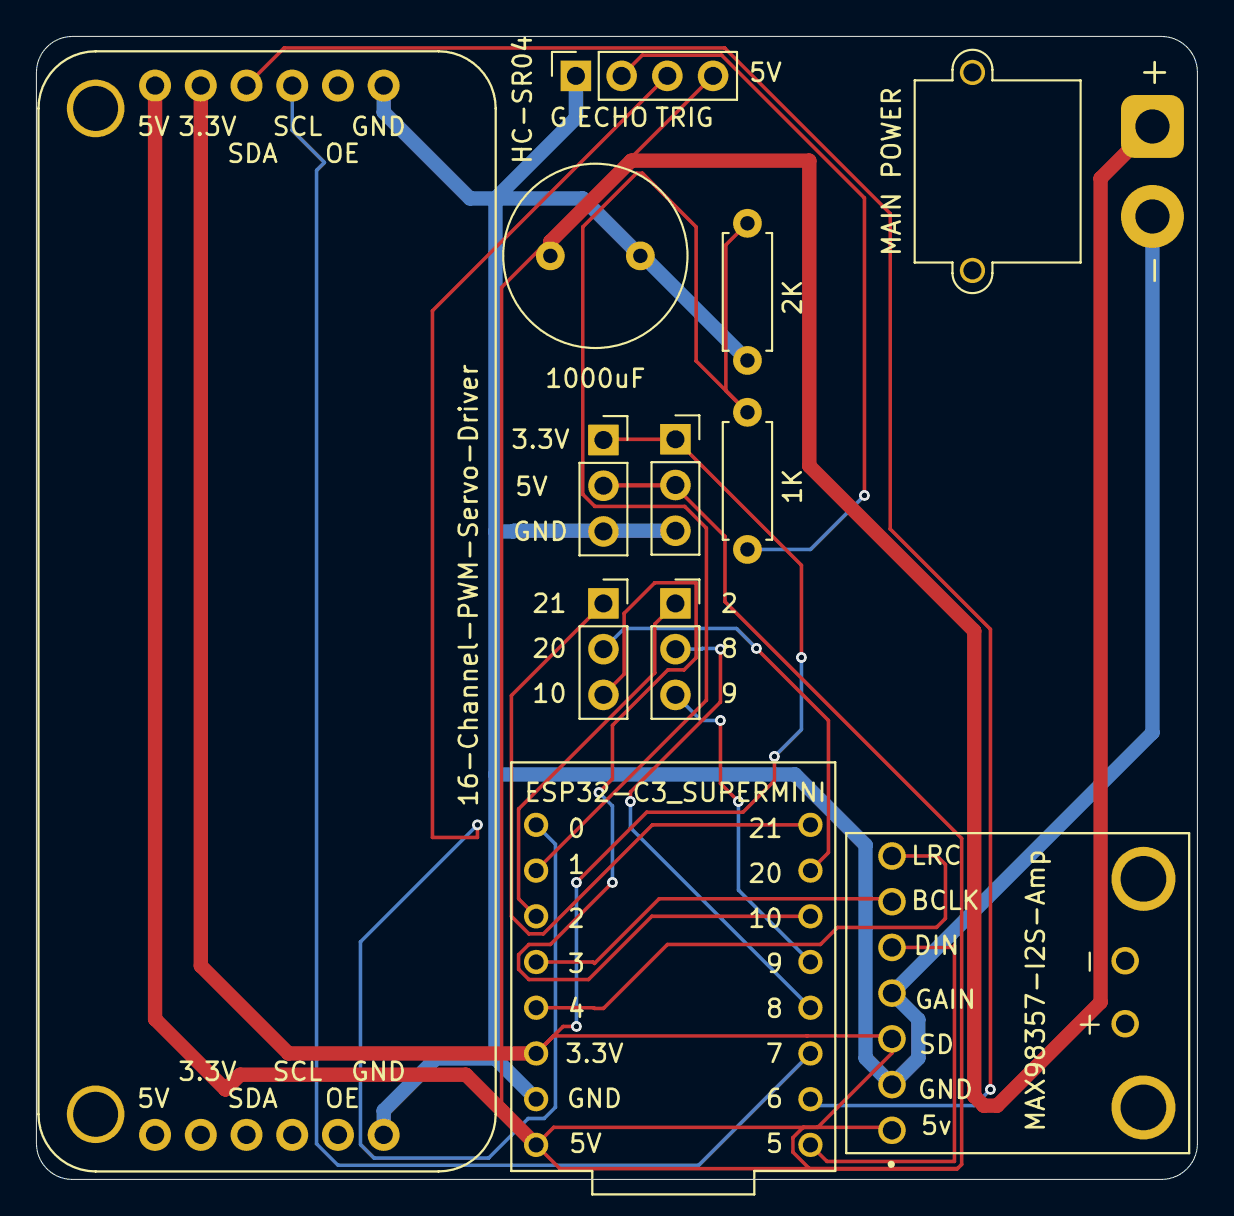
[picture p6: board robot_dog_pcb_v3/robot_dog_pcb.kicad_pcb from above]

Board: 2 copper layers, 64.5 x 63.5 mm, 12 parts (0 on the bottom side), 16 nets.

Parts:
1K: 1k; R_Axial_DIN0207_L6.3mm_D2.5mm_P7.62mm_Horizontal
2K: 2K; R_Axial_DIN0207_L6.3mm_D2.5mm_P7.62mm_Horizontal
5V: Extra power; PinSocket_1x03_P2.54mm_Vertical
16-Channel-PWM-Servo-Driver: PCB ONLY Adafruit-16-Channel-PWM-Servo-Driver-PCB
1000uF: 1000uF; C_Radial_D10.0mm_H12.5mm_P5.00mm
ESP32-C3_SUPERMINI: ESP32-C3_SUPERMINI; MODULE_ESP32-C3_SUPERMINI_TH
GPIO: GPIO; PinSocket_1x03_P2.54mm_Vertical
HC-SR04 : HC-SR04 sensor; PinSocket_1x04_P2.54mm_Vertical
J4: GPIO; PinSocket_1x03_P2.54mm_Vertical
J6: Extra power; PinSocket_1x03_P2.54mm_Vertical
MAIN POWER: AMASS_XT30PW-M_1x02_P2.50mm_Horizontal
MAX98357-I2S-Amp: Adafruit-MAX98357-I2S-Amp-Breakout

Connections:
+5V screw terminal: 5V.1, 5V.2, 16-Channel-PWM-Servo-Driver.V+_1 (V+), 16-Channel-PWM-Servo-Driver.V+_2 (V+), 16-Channel-PWM-Servo-Driver.VCC_1 (VCC), 16-Channel-PWM-Servo-Driver.VCC_2 (VCC), 1000uF.1, ESP32-C3_SUPERMINI.3.3 (3V3), ESP32-C3_SUPERMINI.5V, HC-SR04.4, J6.1, J6.2, MAIN POWER.1 (5V_MAIN), MAX98357-I2S-Amp.JP1_1 (VDD), MAX98357-I2S-Amp.JP1_3 (SD)
/ECHO: 1K.1, HC-SR04.2
/TRIG: ESP32-C3_SUPERMINI.0 (GPIO0), HC-SR04.3
GND: 2K.1, 5V.3, 16-Channel-PWM-Servo-Driver.GND_1 (GND), 16-Channel-PWM-Servo-Driver.GND_2 (GND), 1000uF.2, ESP32-C3_SUPERMINI.G (GND), HC-SR04.1 (GND), J6.3, MAIN POWER.2 (GND_MAIN), MAX98357-I2S-Amp.JP1_2 (GND), MAX98357-I2S-Amp.JP1_4 (GAIN)
unnamed: ESP32-C3_SUPERMINI.21 (GPIO21), GPIO.1
unnamed: ESP32-C3_SUPERMINI.20 (GPIO20), GPIO.2
unnamed: ESP32-C3_SUPERMINI.10 (GPIO10), GPIO.3
unnamed: ESP32-C3_SUPERMINI.2 (GPIO2), J4.1
unnamed: ESP32-C3_SUPERMINI.8 (GPIO8), J4.2
unnamed: ESP32-C3_SUPERMINI.9 (GPIO9), J4.3
unnamed: 1K.2, 2K.2, ESP32-C3_SUPERMINI.1 (GPIO1)
unnamed: ESP32-C3_SUPERMINI.3 (GPIO3), MAX98357-I2S-Amp.JP1_6 (BCLK)
unnamed: ESP32-C3_SUPERMINI.4 (GPIO4), MAX98357-I2S-Amp.JP1_7 (LRCLK)
unnamed: ESP32-C3_SUPERMINI.5 (GPIO5), MAX98357-I2S-Amp.JP1_5 (DIN)
unnamed: 16-Channel-PWM-Servo-Driver.SDA_1 (SDA), 16-Channel-PWM-Servo-Driver.SDA_2 (SDA), ESP32-C3_SUPERMINI.6 (GPIO6)
unnamed: 16-Channel-PWM-Servo-Driver.SCL_1 (SCL), 16-Channel-PWM-Servo-Driver.SCL_2 (SCL), ESP32-C3_SUPERMINI.7 (GPIO7)

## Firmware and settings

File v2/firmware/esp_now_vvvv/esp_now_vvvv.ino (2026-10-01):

// =====================================================================================
//  esp_now_vvvv  —  ESP-NOW proximity -> servo motion -> serial stream for vvvv
// =====================================================================================
//
//  WHAT IT DOES
//  ------------
//  Two ESP32-C3 boards run this SAME sketch. Every ~20 ms each board broadcasts a tiny
//  "PING" packet over ESP-NOW. Each board measures how strong the other board's packets
//  arrive (RSSI, in dBm), turns that into an estimated distance in centimeters, and uses
//  the distance to set how fast a servo sweeps back and forth:
//
//        closer  -> stronger signal -> smaller distance -> FASTER sweep
//        farther -> weaker signal   -> larger distance  -> SLOWER sweep
//
//  Every 20 ms the board also prints ONE data line per motor on the Serial port, in a
//  fixed comma-separated format that a vvvv patch can split and parse directly.
//
//  Builds on esp_now_pingpong (same radio setup) and diagnostics/esp_now_proximity_servo
//  (same sweep idea). Arduino-ESP32 core 3.x. Board: ESP32C3 Dev Module,
//  "USB CDC On Boot: Enabled". Serial: 115200 baud.
//
// -------------------------------------------------------------------------------------
//  SERIAL OUTPUT FORMAT  (this is the part vvvv reads)
// -------------------------------------------------------------------------------------
//  There are only two kinds of lines:
//
//   1) DATA lines — always start with "D," and always have exactly 10 fields:
//
//        D,time_ms,motor,angle_deg,speed_dps,rssi_dbm,rssi_avg_dbm,dist_cm,link,packets
//
//        field  name          meaning
//        -----  ------------  -------------------------------------------------------
//          0    D             line tag: "this is a data line"
//          1    time_ms       millis() on this board when the line was printed
//          2    motor         motor index (0, 1, 2 ...) -> which motor this line is about
//          3    angle_deg     angle the motor was just commanded to (0..180)
//          4    speed_dps     how fast that motor is moving, in degrees per second
//                             (0 = standing still / parked)
//          5    rssi_dbm      raw signal strength of the LAST packet received (e.g. -52)
//          6    rssi_avg_dbm  smoothed signal strength (what the distance is computed from)
//          7    dist_cm       estimated distance to the other board, in centimeters
//          8    link          1 = hearing the other board, 0 = signal lost
//          9    packets       how many packets arrived since the previous data line
//                             (normally 0 or 1 at 20 ms; useful to see packet loss)
//
//        example:  D,48213,0,112.4,135.0,-58,-57.3,142.6,1,1
//
//   2) INFO lines — always start with "#". Human-readable messages (boot info, "signal
//      lost", calibration hints). In vvvv simply IGNORE every line starting with "#".
//
//  Parsing in vvvv (gamma or beta, same idea):
//      SerialPort (115200)  ->  split the incoming text on "\n"  ->  keep only lines that
//      start with "D,"  ->  split each line on ","  ->  convert fields 1..9 to numbers.
//      With several motors you get severala D-lines per 20 ms frame; use field 2 (motor)
//      to route each one to the right place in the patch.
//
// -------------------------------------------------------------------------------------
//  IMPORTANT: ABOUT "SIGNAL STRENGTH -> CENTIMETERS"
// -------------------------------------------------------------------------------------
//  Yes, it is possible, but it is an ESTIMATE, not a measurement. We use the standard
//  "log-distance path loss" model:
//
//        distance_m = 10 ^ ( (RSSI_AT_1M - rssi) / (10 * PATH_LOSS_N) )
//
//    RSSI_AT_1M   = signal strength you measure when the boards are exactly 1 m apart
//    PATH_LOSS_N  = how fast the signal fades with distance (2.0 = open air,
//                   2.5..3.5 = typical room, up to 4 with walls / people in between)
//
//  Realistic expectations: indoors it is roughly right on average but can be off by
//  30-50 % or more. Hands, bodies, the USB cable, antenna orientation and reflections
//  all change RSSI. It works best as "near / medium / far" and for smooth changes, not
//  for precise centimeters. Below ~20 cm the signal saturates, so very close
//  distances all look about the same.
//
//  HOW TO CALIBRATE (5 minutes, makes a big difference):
//    1. Put the boards exactly 1 m apart, same height, antennas facing the same way.
//       Watch field 6 (rssi_avg_dbm) for ~10 s and write down the typical value.
//       -> put it in RSSI_AT_1M.
//    2. Move them to 3 m apart and write down rssi_avg_dbm again (call it R3).
//       -> PATH_LOSS_N = (RSSI_AT_1M - R3) / 4.77      (4.77 = 10 * log10(3))
//    3. If you change TX_POWER later, redo step 1 (the whole curve shifts).
//
// =====================================================================================

#include <WiFi.h>
#include <esp_now.h>
#include <esp_wifi.h>
#include <math.h>

// =====================================================================================
//  1. SETTINGS YOU WILL WANT TO TWEAK
// =====================================================================================

// ---------- Timing ----------
#define SEND_INTERVAL_MS   20     // send one PING every 20 ms (= 50 packets per second)
#define SEND_JITTER_MS     3      // + random 0..3 ms, so both boards don't always transmit
                                  //   at the exact same instant and collide
#define FRAME_MS           20     // update the motors AND print data lines every 20 ms
                                  //   (20 ms = 50 Hz, which is also the servo's own refresh rate)
#define LOST_MS            1000   // no packet for this long -> link = 0, motors park

// ---------- Radio ----------
#define WIFI_CHANNEL       1      // both boards MUST use the same channel
#define TX_POWER           WIFI_POWER_8_5dBm   // what worked in esp_now_pingpong.
                                               // Changing this changes RSSI_AT_1M!

// ---------- Distance estimate (calibrate, see header) ----------
#define RSSI_AT_1M        -88.0f  // dBm measured at 1 m  (CALIBRATE)
#define PATH_LOSS_N        2.5f   // environment factor   (CALIBRATE)
#define DIST_MIN_CM        5.0f   // clamp: never report less than this
#define DIST_MAX_CM        1000.0f// clamp: never report more than this
#define RSSI_SMOOTH        0.10f  // 0..1. Smoothing of RSSI before converting to cm.
                                  //   Lower = steadier but slower to react.
                                  //   At 50 packets/s, 0.10 settles in roughly 0.5 s.
#define R3                 -94.0f

// ---------- Distance -> motor speed ----------
#define NEAR_CM            20.0f  // at this distance (or closer) motors run at SPEED_MAX_DPS
#define FAR_CM             300.0f // at this distance (or farther) motors run at SPEED_MIN_DPS
#define SPEED_MAX_DPS      250.0f // degrees per second when near
#define SPEED_MIN_DPS      15.0f  // degrees per second when far

// ---------- Servo hardware ----------
#include <Wire.h>
#include <Adafruit_PWMServoDriver.h>
#define SDA_PIN            6      // PCA9685 SDA (see v2/README pin map)
#define SCL_PIN            7      // PCA9685 SCL
#define SERVO_FREQ         50     // standard analog servo frequency
#define PULSE_MIN_US       600    // pulse width at 0 deg
#define PULSE_MAX_US       2400   // pulse width at 180 deg
Adafruit_PWMServoDriver pca(0x40);

// =====================================================================================
//  2. MOTORS
// =====================================================================================
//  Each motor is described by one entry in the MOTORS[] table. Right now there is only
//  ONE motor. To add more later, just add lines to the table — the rest of the code
//  (sweeping, printing one D-line per motor) already loops over the whole table.
//
//  Later, for sequences/gaits, you would replace the simple back-and-forth sweep in
//  updateMotors() with your own pattern, but keep the same printing.

struct Motor {
  uint8_t channel;     // PCA9685 output channel (0..15) the servo is plugged into
  float   angleMin;    // sweep limit A (degrees)
  float   angleMax;    // sweep limit B (degrees)
  float   angleRest;   // where the motor parks when the link is lost
  // --- runtime state (filled in by the code, leave at 0 in the table) ---
  float   angle;       // current commanded angle
  int8_t  dir;         // +1 = moving toward angleMax, -1 = toward angleMin
  float   speedDps;    // current speed in degrees/second
};

Motor MOTORS[] = {
  //  ch  min   max   rest
  {   0,  45,  135,   90 },
  // {   1,  45,  135,   90 },   // <- example: uncomment to add a second motor on channel 1
};
const int NUM_MOTORS = sizeof(MOTORS) / sizeof(MOTORS[0]);

// Convert an angle in degrees to a pulse and send it to the PCA9685.
void writeServo(uint8_t channel, float deg) {
  deg = constrain(deg, 0.0f, 180.0f);
  uint32_t us = PULSE_MIN_US + (uint32_t)((PULSE_MAX_US - PULSE_MIN_US) * (deg / 180.0f));
  pca.writeMicroseconds(channel, us);
}

// =====================================================================================
//  3. ESP-NOW MESSAGES
// =====================================================================================
//  We only need one message type now: PING. (No PONG reply like in esp_now_pingpong:
//  each board measures the RSSI of the OTHER board's pings, which is all we need, and
//  skipping replies halves the radio traffic at this fast rate.)

enum MsgType : uint8_t { MSG_PING = 1 };

typedef struct __attribute__((packed)) {
  uint8_t  type;     // MSG_PING
  uint32_t seq;      // counts up by 1 each send
} Msg;

uint8_t BCAST[6] = {0xFF, 0xFF, 0xFF, 0xFF, 0xFF, 0xFF};   // broadcast: no MACs needed

// ---- Receive queue ----
// The receive callback runs in the WiFi task, NOT in loop(). It must be quick, so it only
// copies the RSSI into this small ring buffer. loop() reads the buffer and does the real work.
#define QSIZE 16
volatile int8_t  rxRssi[QSIZE];
volatile uint8_t qHead = 0, qTail = 0;

void onRecv(const esp_now_recv_info_t *info, const uint8_t *data, int len) {
  if (len != sizeof(Msg) || data[0] != MSG_PING) return;   // ignore anything unexpected
  uint8_t next = (qHead + 1) % QSIZE;
  if (next == qTail) return;                               // queue full -> drop this one
  rxRssi[qHead] = info->rx_ctrl->rssi;
  qHead = next;
}

uint32_t seqNo = 0;

void sendPing() {
  Msg m = { MSG_PING, ++seqNo };
  esp_now_send(BCAST, (uint8_t *)&m, sizeof(m));
  // We don't print send errors here: at 50 sends/s that would flood the serial port
  // and break the clean data stream for vvvv.
}

// =====================================================================================
//  4. PROXIMITY STATE  (signal strength -> distance -> speed)
// =====================================================================================

int      rssiLast   = 0;          // raw RSSI of the newest packet
float    rssiAvg    = 0;          // smoothed RSSI
float    distCm     = DIST_MAX_CM;
bool     everHeard  = false;
bool     linkUp     = false;
uint32_t lastHeard  = 0;          // millis() of the newest packet
uint16_t packetsThisFrame = 0;    // packets received since the last D-line

// Signal strength (dBm) -> estimated distance (cm), using the log-distance model.
float rssiToCm(float rssi) {
  float meters = powf(10.0f, (RSSI_AT_1M - R3) / (10.0f * PATH_LOSS_N));
  return constrain(meters * 100.0f, DIST_MIN_CM, DIST_MAX_CM);
}

// Distance (cm) -> motor speed (deg/s). Linear between NEAR_CM and FAR_CM.
float cmToSpeed(float cm) {
  float t = (cm - NEAR_CM) / (FAR_CM - NEAR_CM);   // 0 at NEAR_CM, 1 at FAR_CM
  t = constrain(t, 0.0f, 1.0f);
  return SPEED_MAX_DPS + t * (SPEED_MIN_DPS - SPEED_MAX_DPS);
}

// Called once per received packet (from loop(), not from the callback).
void handlePacket(int rssi) {
  rssiLast = rssi;
  // Exponential moving average: move rssiAvg a fraction of the way toward the new value.
  // We smooth in dBm (before converting to cm) because RSSI noise is roughly even in dBm.
  if (!everHeard) { rssiAvg = rssi; everHeard = true; }
  else            { rssiAvg += RSSI_SMOOTH * (rssi - rssiAvg); }

  distCm    = rssiToCm(rssiAvg);
  lastHeard = millis();
  packetsThisFrame++;

  if (!linkUp) {
    linkUp = true;
    Serial.println("# link up");
  }
}

// =====================================================================================
//  5. MOTOR UPDATE + DATA OUTPUT  (runs every FRAME_MS)
// =====================================================================================

uint32_t lastFrame = 0;

// Print one D-line for motor i. See the format table at the top of the file.
void printDataLine(int i) {
  Serial.printf("D,%lu,%d,%.1f,%.1f,%d,%.1f,%.1f,%d,%u\n",
                (unsigned long)millis(),
                i,
                MOTORS[i].angle,
                MOTORS[i].speedDps,
                rssiLast,
                rssiAvg,
                distCm,
                linkUp ? 1 : 0,
                packetsThisFrame);
}

void updateMotors() {
  uint32_t now = millis();
  if (now - lastFrame < FRAME_MS) return;          // not time yet
  float dt = (now - lastFrame) / 1000.0f;          // seconds since last frame (~0.020)
  lastFrame = now;

  // Link lost? Park every motor once and report speed 0.
  if (linkUp && now - lastHeard > LOST_MS) {
    linkUp = false;
    Serial.println("# link lost: motors parked");
    for (int i = 0; i < NUM_MOTORS; i++) {
      MOTORS[i].angle    = MOTORS[i].angleRest;
      MOTORS[i].speedDps = 0;
      writeServo(MOTORS[i].channel, MOTORS[i].angle);
    }
  }

  float speed = linkUp ? cmToSpeed(distCm) : 0;

  for (int i = 0; i < NUM_MOTORS; i++) {
    Motor &m = MOTORS[i];
    m.speedDps = speed;

    if (linkUp) {
      // Move "speed * time" degrees in the current direction, bounce at the limits.
      m.angle += m.dir * m.speedDps * dt;
      if (m.angle >= m.angleMax) { m.angle = m.angleMax; m.dir = -1; }
      if (m.angle <= m.angleMin) { m.angle = m.angleMin; m.dir = +1; }
      writeServo(m.channel, m.angle);
    }

    printDataLine(i);      // print every frame, even when parked, so vvvv gets a steady stream
  }

  packetsThisFrame = 0;
}

// =====================================================================================
//  6. SETUP + LOOP
// =====================================================================================

uint32_t nextPing = 0;

void setup() {
  Serial.begin(115200);
  delay(1000);

  // --- Servos ---
  Wire.begin(SDA_PIN, SCL_PIN);
  pca.begin();
  pca.setPWMFreq(SERVO_FREQ);
  delay(10);
  for (int i = 0; i < NUM_MOTORS; i++) {
    MOTORS[i].angle    = MOTORS[i].angleRest;
    MOTORS[i].dir      = +1;
    MOTORS[i].speedDps = 0;
    writeServo(MOTORS[i].channel, MOTORS[i].angle);
  }

  // --- Radio (same recipe as esp_now_pingpong) ---
  WiFi.mode(WIFI_STA);                 // station mode, no router needed
  WiFi.disconnect();
  WiFi.setTxPower(TX_POWER);
  esp_wifi_set_channel(WIFI_CHANNEL, WIFI_SECOND_CHAN_NONE);

  if (esp_now_init() != ESP_OK) {
    Serial.println("# ESP-NOW init failed");
    while (1) delay(1000);
  }
  esp_now_register_recv_cb(onRecv);

  esp_now_peer_info_t peer = {};
  memcpy(peer.peer_addr, BCAST, 6);
  peer.channel = 0;                    // 0 = current channel
  peer.encrypt = false;
  esp_now_add_peer(&peer);

  // --- Info lines (start with '#', vvvv ignores them) ---
  Serial.print("# my MAC: "); Serial.println(WiFi.macAddress());
  Serial.printf("# channel %d, send every %d ms, %d motor(s)\n", WIFI_CHANNEL, SEND_INTERVAL_MS, NUM_MOTORS);
  Serial.printf("# calibration: RSSI_AT_1M=%.1f  PATH_LOSS_N=%.2f\n", RSSI_AT_1M, PATH_LOSS_N);
  Serial.println("# format: D,time_ms,motor,angle_deg,speed_dps,rssi_dbm,rssi_avg_dbm,dist_cm,link,packets");

  randomSeed(esp_random());
  nextPing  = millis() + random(0, SEND_INTERVAL_MS);
  lastFrame = millis();
}

void loop() {
  // 1) Send our PING every ~20 ms
  if ((int32_t)(millis() - nextPing) >= 0) {
    nextPing = millis() + SEND_INTERVAL_MS + random(0, SEND_JITTER_MS + 1);
    sendPing();
  }

  // 2) Process every packet that arrived since last time
  while (qTail != qHead) {
    int rssi = rxRssi[qTail];
    qTail = (qTail + 1) % QSIZE;
    handlePacket(rssi);
  }

  // 3) Every 20 ms: move the motors and print the D-lines
  updateMotors();
}

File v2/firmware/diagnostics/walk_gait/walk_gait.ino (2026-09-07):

/*
 * WALK GAIT  —  smooth, live-tunable quadruped gait
 * ==================================================
 * Same hardware as motors_only.ino: PCA9685 @ 0x40, OE on GPIO10, I2C 6/7.
 *
 * ROBOT: quadruped, ONE servo per leg (1 DOF each).  Channel map:
 *        ch0 = BL  (back-left)
 *        ch1 = BR  (back-right)
 *        ch2 = FL  (front-left)    <- j3
 *        ch3 = FR  (front-right)   <- j2
 *        front = the end with the distance sensor. (channel 4 unused / not wired)
 *
 * HOW IT MOVES
 *   Each leg follows a smooth sine wave:
 *       pulse = center + DIR * AMP * sin( 2*pi*t/PERIOD + PHASE )
 *   With only 1 DOF per leg you can't pick a foot up, so "walking" is a
 *   phase-offset swing: the legs sweep fore/aft in a coordinated pattern and
 *   the robot shuffles forward.  The whole trick is in two per-leg knobs:
 *       DIR   = which way is "forward" for THAT servo (+1 or -1)   <-- mirror L/R
 *       PHASE = when in the stride that leg swings (degrees)       <-- the gait
 *
 * >>> YOU DO NOT NEED TO RECOMPILE TO TUNE. <<<
 *   Open Serial Monitor @115200, newline ending, and type commands (send '?').
 *   Change amplitude / phase / direction / period / trim live while it walks,
 *   then copy the final numbers into the DEFAULTS block below to keep them.
 *
 * SAFETY: every command is clamped to [SAFE_MIN, SAFE_MAX] so a servo can
 *   never be driven into a mechanical stall.  Widen these only once you know
 *   the real end-stops of your legs.
 */

#include <Wire.h>
#include <Adafruit_PWMServoDriver.h>

// ---------- hardware ----------
#define PIN_SDA 6
#define PIN_SCL 7
#define PIN_OE  10          // active-LOW output enable
#define SERVO_FREQ 50
Adafruit_PWMServoDriver pwm = Adafruit_PWMServoDriver(0x40);

// ---------- pulse calibration (PCA9685 counts, 0..4095 @ 50 Hz) ----------
#define CENTER   307        // ~1.5 ms neutral  (same as motors_only)
#define SAFE_MIN 160        // hard floor: never command below this
#define SAFE_MAX 455        // hard ceiling: never command above this

// ---------- legs ----------
#define NLEGS 4
enum { BL = 0, BR = 1, FR = 2, FL = 3 };            // array index (NOT channel)
const char*   LEG_NAME[NLEGS] = { "BL", "BR", "FR", "FL" };
const uint8_t LEG_CH[NLEGS]   = {  0,    1,    3,    2  };  // idx2->ch3(FR), idx3->ch2(FL)

// ================= DEFAULTS — edit these to make tuning permanent =========
int   legCenter[NLEGS] = {  357,    392,    387,    372  }; // measured per-leg neutral (BL,BR,FR,FL)
int   legAmp[NLEGS]    = {   55,     55,     55,     55   }; // swing size, counts
float legPhase[NLEGS]  = {    0,    180,      0,    180   }; // diagonal trot: (BL,FR)=0  (BR,FL)=180
int   legDir[NLEGS]    = {   +1,     -1,     -1,     +1   }; // left(BL,FL)=+1  right(BR,FR)=-1  (guess)
float periodMs         = 1200;                              // ms per full stride
// ==========================================================================

bool  running  = false;     // gait on/off
float ampScale = 0.0;       // 0..1 ease-in/out so starts & stops are gentle

// ---------- waveform mode ----------
//  0 = SINE  : smooth continuous trot, every leg always moving (default)
//  1 = CREEP : one diagonal STROKES while the other HOLDS planted, then they swap.
//              Each active leg does a raised-cosine "flick" (center -> amp -> center)
//              during its window, and sits at center the rest of the time.
int   waveMode  = 0;
float swingFrac = 0.5;      // CREEP: fraction of the cycle a leg spends stroking
                            //   0.5 = pairs alternate with no overlap (what you asked for)
                            //   <0.5 = a pause with all legs planted between strokes
                            //   >0.5 = the two strokes overlap a little

// ---------- I2C scan (handy sanity check) ----------
void scanI2C() {
  Serial.println("[I2C] scanning...");
  bool found = false;
  for (byte a = 1; a < 127; a++) {
    Wire.beginTransmission(a);
    if (Wire.endTransmission() == 0) { Serial.print("  found 0x"); Serial.println(a, HEX); found = true; }
  }
  if (!found) Serial.println("  NONE found! (check wiring/power)");
}

// ---------- gait presets: just phase tables (degrees), enum order LB,RB,LF,RF ----------
void preset(const char* name) {
  if      (!strcmp(name, "trot"))  { float p[]={0,180,  0,180}; memcpy(legPhase,p,sizeof(p)); waveMode=0; } // diagonal, all legs moving
  else if (!strcmp(name, "creep")) { float p[]={0,180,  0,180}; memcpy(legPhase,p,sizeof(p)); waveMode=1; } // diagonal, ONE pair strokes while other holds
  else if (!strcmp(name, "walk"))  { float p[]={0, 90,180,270}; memcpy(legPhase,p,sizeof(p)); waveMode=0; } // one leg at a time
  else if (!strcmp(name, "pace"))  { float p[]={0,180,180,  0}; memcpy(legPhase,p,sizeof(p)); waveMode=0; } // left pair / right pair
  else if (!strcmp(name, "bound")) { float p[]={0,  0,180,180}; memcpy(legPhase,p,sizeof(p)); waveMode=0; } // back pair / front pair
  else { Serial.println("presets: trot | creep | walk | pace | bound"); return; }
  Serial.print("preset -> "); Serial.println(name);
}

void printStatus() {
  Serial.println("---- status ----");
  Serial.print("running="); Serial.print(running ? "YES" : "no");
  Serial.print("  period="); Serial.print(periodMs); Serial.println(" ms");
  for (int i = 0; i < NLEGS; i++) {
    Serial.print("  ["); Serial.print(i); Serial.print("] ");
    Serial.print(LEG_NAME[i]); Serial.print(" ch"); Serial.print(LEG_CH[i]);
    Serial.print("  center="); Serial.print(legCenter[i]);
    Serial.print("  amp=");    Serial.print(legAmp[i]);
    Serial.print("  phase=");  Serial.print(legPhase[i]);
    Serial.print("  dir=");    Serial.println(legDir[i]);
  }
}
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

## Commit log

2026-06-12 Initial upload
    [cover.stl, leg.stl, main_body.stl]
2026-07-28 adding pcb design
    [robot_dog_pcb.kicad_pcb, robot_dog_pcb.kicad_sch]
2026-07-29 Restructure: move original robot into v1/ (Feather ESP32 V2)
    Nest the Phase-1 pose-based project (README, docs, src) under v1/ so a second hardware generation can live beside it. Shared assets (robot_dog_pcb/, little_robot_original_3d_stl/) stay at the repo ro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
2026-07-29 Add v2 firmware: ESP32-C3 SuperMini bring-up (walk + obstacle-stop + voice)
    Second hardware generation on the ESP32-C3 SuperMini. Flagship little_dog_walk trots via diagonal servo pairs, freezes when an obstacle is <10 cm, and plays a synthesized dial-up-modem voice on the stop edge. Also: full 5-part test (little_dog_test_1), flag-based staged test (little_dog_test_v2), the earlier obstacle_stop demo, and six per-subsystem diagnostic sketches (esp32_alive, motors_only, hold_center, distance_only, audio_only, modem_chirp).
    Key fixes baked in: OE left on the PCA9685 onboard pulldown (unconnected); I2S write uses a finite timeout so the chirp can never hang; MAX98357A enabled via SD->3.3V.
    C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
    [audio_only.ino, distance_only.ino, esp32_alive.ino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]
2026-07-29 Add v2 bring-up documentation (wiring schematic + learnings)
    HANDOFF_WIRING.md: ASCII system schematic, pin map, power rails, common-ground star node, echo divider. HANDOFF_LEARNINGS.md: the debugging lessons (OE twitch, 13 mA = no signal, current-limit-is-not-a-push, common ground, USB CDC On Boot, I2S hang, MAX98357A silence/SD pin) plus the sketch inventory and open tasks (leg-map verification).
2026-07-29 Add top-level & v2 READMEs and .gitignore
    Top-level README frames the two generations (v1 Feather/pose-based vs v2 ESP32-C3/walk+sensor+voice) and the shared body + PCB. v2/README covers hardware, pin map, flashing (ESP32C3 Dev Module + USB 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
2026-07-29 Add v3 KiCad carrier workspace (matches robot v2)
    Copy of the carrier project as a v3 working area (robot_dog_pcb_v3/), plus WIRING_GUIDE.md: the modules-as-pluggable-headers design, the verified v2 net map, the 2S-LiPo + XL4005 power plan, and a net-by-net correction list to align the schematic with the working firmware (SDA=GPIO6/SCL=GPIO7, I2S DIN=GPIO5, amp SD->3V3, GAIN->GND, OE no-connect, 1k/2k ECHO divider). Module footprints confirmed as 2.54mm thru-hole headers.
    [robot_dog_pcb.kicad_pcb, robot_dog_pcb.kicad_sch]
2026-08-02 design with pin placement, extra pins and traces done
    [robot_dog_pcb.kicad_pcb, robot_dog_pcb.kicad_sch]
2026-08-05 corrected pcb flags and wiring
    [robot_dog_pcb.kicad_pcb, robot_dog_pcb.kicad_sch]
2026-09-05 adding recomendations for first boot on ESP32CSMINI
2026-09-06 adding last version of printed pcb board
    [bom.csv, designators.csv, positions.csv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]
2026-09-07 testing 4 legs
